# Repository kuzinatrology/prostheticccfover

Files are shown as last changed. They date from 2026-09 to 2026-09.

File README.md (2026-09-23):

# Prosthetic cover configurator

A prototype web configurator for cosmetic covers. Four tabs, one per cover,
differing in where the shape comes from: **below knee** (transtibial, the
shape of the leg set by sliders), **above knee** (transfemoral, College Park
Capital knee, the shape taken from a scan of the other leg), **anatomic
shank** (built by the offline pipeline in `anatomic/` from the prosthesis scan
and a MakeHuman shank), and **iteration 1** (a cover modelled in Rhino and
handed to the configurator as a file). Move the sliders, watch the cover turn,
read its weight, download a print file. The transfemoral and the modelled tabs
have their own sections below; everything else here applies to all of them.

The whole point of the build is the last mile: **a design that fails a
printability check is not reachable**. Every constraint is built into the
generator so no slider combination can produce one, and the interface never
tells anybody their design was rejected.

## Running it

```bash
python3 -m venv .venv && .venv/bin/pip install -r requirements.txt
.venv/bin/python -m uvicorn backend.app:app --port 8000     # geometry service
cd frontend && npm install && npm run dev                   # http://localhost:5173
```

`npm run build` puts the page in `frontend/dist`, and the service serves it
from the same port, so a built copy needs only the one process.

### Leaving it running

On macOS a launch agent keeps the service up, so the page is always at the same
address rather than only while a terminal is open:

The plist ships with a placeholder path in it; point it at wherever this is
checked out before loading it.

```bash
cp deploy/com.cover.configurator.plist ~/Library/LaunchAgents/
launchctl bootstrap gui/$(id -u) ~/Library/LaunchAgents/com.cover.configurator.plist
echo '127.0.0.1  cover.test' | sudo tee -a /etc/hosts   # http://cover.test:8000
```

`.test` rather than `.local`: macOS hands `.local` to Bonjour, and an
`/etc/hosts` entry there resolves only sometimes. `.test` is reserved for
exactly this and always does.

The agent binds `0.0.0.0`, so anybody on the same network opens it at
`http://<this machine's address>:8000`. That address comes from DHCP and can
move; reserve it on the router if it needs to stay put. `cover.test` is a line
in *this* machine's `/etc/hosts` and means nothing to anyone else's.

Nothing beyond the network is a boundary here: there is no sign-in, and every
rebuild is a couple of seconds of CPU with one worker behind it. Fine among
people who share a router, not something to put on the open internet as it
stands.

The agent has `RunAtLoad` and `KeepAlive`, so it starts at login and comes back
if it dies. It logs to `~/Library/Logs/cover-configurator.log`. To stop it,
`launchctl bootout gui/$(id -u)/com.cover.configurator`; to start it again,
`bootstrap` the same file. The port stays 8000 because binding 80 would mean
running the geometry service as root, which is not worth a shorter address.

Or skip the web app entirely:

```bash
.venv/bin/python -m backend.cli --preset chevron -o cover.3mf
.venv/bin/python -m backend.cli --image leaf.png -o leaf.3mf
.venv/bin/python -m backend.cli --operation emboss --relief-profile dome -o scales.3mf
.venv/bin/python -m backend.cli --help
```

Tests:

```bash
.venv/bin/python -m pytest tests -q
COVER_EXAMPLES=200 .venv/bin/python -m pytest tests -q      # a longer hunt
```

## Personal cabinet

The configurator now supports individual accounts. Open **Sign in / create
account** in the upper-right corner to register or sign in. The cabinet can
save the current parameter set under a name, reopen it later, and delete old
designs. Only the owner can delete a design; saved designs are publicly visible
in the community catalogue. If a design uses an uploaded image, the original
image bytes are stored with that design so it remains available after a server
restart.

For a deployed instance, set `COVER_SESSION_SECRET` to a long random value
before starting the service. The SQLite database is created at
`backend/configurator.sqlite3` and should be backed up with the rest of the
application data.

The **Community** button opens the public design catalogue. It includes every
saved design with its author nickname, a search by design name, visible 1–5
ratings, and a participant leaderboard based on average design rating. A user
can rate a design once and change that rating later.

Every nickname and design author links to `/profile/<user-id>`. Public profiles
show optional personal information, a year-long activity heatmap, and all of
the user's designs with their ratings. Profile fields are edited in the
owner's profile page; guests can only view them.

The profile avatar can be changed by clicking it and selecting an image. PNG,
JPEG, WebP and other Pillow-readable image files up to 2 MB are accepted. The
image is stored with the account and is also shown beside the nickname in the
header after sign-in.

The main screens have stable routes:

- `/workshop` — the cover configurator;
- `/profile/<user-id>` — a public user profile.

A saved design belongs to the tab it was drawn on. The tabs do not share a
parameter set -- the transtibial cover has no pylon diameter and Iteration 2 has
no calf bulge -- so each design records its tab and is read back through that
tab's own parameters. Opening a design from another tab reloads the page onto
that tab; in the catalogue such designs carry the tab's name beside them.

The header keeps **Workshop**, **Community**, and **Profile** in one responsive
navigation row. Guests also see **Sign in / Register**. After sign-in, that
button becomes the user's avatar and nickname and opens their profile; for a
guest, a profile is opened by clicking a user in Community or by visiting its
public URL.

## The four axes

A design is not a list of pattern types. It is four independent things
multiplied together, and the variety comes from the product:

```
cell field (u,v)  x  operation  x  mask (u,v)  x  finish
```

**Cell field.** Where the cells are and what shape they are: density and its
gradient, irregularity, stretch, lean, corner rounding, strut width.

**Operation.** What is done with those cells. `cut` drives prisms through the
wall and removes them. `emboss` and `engrave` displace the outer surface and
touch no boolean at all. `none` leaves the shell smooth.

**Mask.** Where the pattern lives: everywhere, in a band, on a panel front and
back, or in stripes. The edge is feathered, and that feathering is the point:
a hard edge reads as a cropped picture, a soft one reads as a designed object.

**Finish.** How it is shaded in the viewer. Flat, a gradient between two
palette colours, or faceted. None of it touches the mesh, so weight and print
file are identical across all three.

Six presets in `backend/presets.py` are starting points on those axes. Picking
one moves the sliders and lets go: nothing is locked afterwards, and the strip
stops marking a preset the moment the design has moved off it.

### The hole can be a picture

`samples/` holds a few drawings to try it on, written out of `tests/shapes.py`:
a ring whose middle would fall out, a comb whose prongs are narrower than a
strut, a disc with a whisker four pixels across.

`HOLE SHAPE: [CELLS] [IMAGE]` is not a fifth axis. Upload a leaf, a logo, a
silhouette, and it decides what a hole *looks like*; the cell field still
decides where the holes are and how big. So there is no new slider for "one
big motif or many small ones" — that is the density slider, relabelled, and
the mask, the gradient, the stretch and the lean all keep working untouched.

`backend/motif.py` reads the file. The alpha channel is believed where there
is one, because a cut-out carries its own silhouette and no threshold beats
it; otherwise Otsu's method splits the histogram and `threshold_bias` slides
that split, since on a photograph the automatic answer is often a little off
and this is the only way to put it right by hand. Whatever runs around the
border of the picture is the background. Marching squares traces the contours,
nesting sorts outlines from holes, and what comes out is a polygon in the unit
square. The file stays in memory for the session; the design carries only its
digest, which is also what goes on the spec line so the same picture and the
same sliders rebuild the same cover.

The panel shows the silhouette it read, beside the drop zone, before anything
is cut. That preview is the feature, not an ornament: without it the upload is
a black box, a cover comes back carrying something that does not look like the
picture, and there is no way to tell whether the threshold missed or the file
was wrong.

## How the geometry is put together

`backend/surface.py` builds the outer surface. The section is a superellipse,
so its sides can flatten, and its centre slides backward where the calf swells,
so the calf grows behind while the front of the shank stays where it was. The
section is walked at **equal arc length** rather than equal angle: a
superellipse parameterised by angle races through the ends of its axes, which
would stretch every cell sitting near one.

`backend/fields.py` holds the scalar fields. Density and mask are the same kind
of object, a function of (u, v) returning a number in [0, 1].

`backend/pattern.py` lays out the cells in a conformal ("Mercator") image of
the cover, `U = 2πu` and `V = ∫L dv/r(v)`, where the metric is
`r(v)²(dU² + dV²)`. A round cell there is a round cell on the cover, and cells
grow with the cover's girth.

Stretch and lean add one layer on top: seeds are laid out in a *lattice* space
and carried into the domain by a linear warp with determinant one. Cell areas
survive it, so cell counts do; adding a full turn to `U` is a pure shift in
that space, so the seam still closes however far the pattern leans; and the
cells are carried into the domain *before* anything is measured, so no
printability rule ever sees the warp.

`backend/relief.py` is the whole of emboss and engrave. For a Voronoi diagram
the distance to a cell boundary is exactly half the gap between the two nearest
seeds, so two nearest-neighbour queries give the height everywhere, and the
shell is built from a displaced grid.

`backend/mesh_build.py` closes a solid between any two grids, drives a prism
through the wall for every hole, and removes them all with one `manifold3d`
boolean. `backend/generator.py` ties it together and produces the notes.

Two details in the prisms earn their keep. A prism's caps are flat while the
wall is curved, so each cap is laid on the surface and subdivided until no
triangle outruns the curvature; without it the middle of a wide hole keeps a
lens of material floating free of the cover. And a prism's side wall is a
straight chord where the hole's edge is really a curve, so it bows into the
strut: long edges are split until that bow is small, and the remainder is paid
back in the erosion.

A cell's own hole is convex, and a cone of triangles from its centre is the
cheapest cap that covers it. A motif's hole is whatever the picture was, and a
cone from any single point folds over itself on a shape like a letter C. Those
caps are triangulated instead — a constrained Delaunay triangulation fills the
ring exactly, using the ring's own vertices, then red-green refinement splits
it until no edge outruns the same chord. Which builder a ring goes to is read
off the ring, so the cell field's own output is built exactly as it was
before, and a motif that happens to be convex costs nothing extra.

### The density field

Pattern density is a **function**, not a number:

```python
def build_cells(surface, density: Callable[[float, float], float], ...)
```

The two sliders build one. So does the mask, which is the same kind of object
used at a different point. A stress field from an FE run, or a mask painted in
the interface, is a one-line change in `fields.py`; nothing under it ever sees
a scalar.

### Irregularity

One code path covers both ends of the slider. A graded hexagonal lattice is
built from the spacing field, every node is displaced by `irregularity` times a
random offset, and the variable disk radius is then enforced directly by
pushing apart any pair that ended up too close. At 0 the lattice is untouched;
at 1 the nodes are as scattered as the spacing allows. Two damped relaxation
passes absorb the seams where the lattice has to change its column count — a
clean lattice is a fixed point of that operation, so the ordered end stays
ordered.

## The guarantees, and where each one lives

| Rule | How it cannot be broken |
|---|---|
| Strut ≥ `MIN_STRUT` | The hole *is* the cell eroded by `strut/2`, measured in mm at the cell's tightest scale. There is nothing to check. |
| Cell too small to erode | Erosion returns empty, the cell stays solid. Silently. |
| Hole < `MIN_HOLE` | Inscribed radius via `polylabel`; below the limit the cell stays solid. Silently. |
| Hole > `a_max` | The cell's seed is replaced by three and the neighbourhood is rebuilt finer. The pattern gets smaller there, not different. |
| Corner rounding | An opening (`buffer(-r).buffer(+r)`) can only take material away, so no rule needs re-checking after it. |
| Mask feathering | Fading the mask deepens the same erosion. Half a mask is half a cell gone, whatever the cell's size, and a mask at zero closes it completely. |
| Wall vs curvature | `wall_thickness`'s upper bound is recomputed from the surface's smallest radius of curvature and sent to the panel, which shortens the slider's track. |
| Groove vs wall | `relief_depth`'s upper bound is 60% of the wall when engraving, by the same moving-track mechanism. Embossing has no ceiling: it removes nothing. |
| One connected piece | Voronoi edges form a connected graph, so the shell cannot fall apart. Confirmed by genus: it comes out at exactly one per hole plus one for the tube. |
| Mesh edges eating the strut | Ring edges are split until their bow is under a fixed fraction of the strut, and the erosion is widened by exactly that fraction. |
| A picture's own thin details | The motif is opened by `MIN_HOLE/2`. An opened shape is a union of discs of that radius, so nothing in it can be thinner. |
| A picture's own thin gaps | The motif is then closed by `strut/2`. The complement of a closed shape is a union of discs, so no gap in it can be narrower. |
| A motif wider than the wall | Its own fill is cut back in that cell and it is laid again. Subdividing is for cells; half a leaf is not a leaf. |
| A hole inside a hole | Filled. It is a disc of shell with nothing holding it, and it would drop out of the print. |

`a_max` is `STIFFNESS_C · t^1.5` (a plate deflects as span² and stiffens as
t³), capped by the bridging limit relaxed by an arch factor, and capped again
at 90% of the surface's radius of curvature so a hole cannot outgrow the wall
it is cut through. A squarer section curves harder at its corners, so it gets
a finer pattern; that is the physics, not a rule bolted on.

Every millimetre-to-domain conversion is **measured from the surface**, not
guessed from the section's half-widths. That was an ellipse-only shortcut, and
it stopped being an upper bound the moment the section could be a superellipse.

When something does move, the panel says so as a property of the object —
`Struts widened to 0.8 mm`, `Relief held at 1.4 mm by the wall`, `Pattern
refined across 12 cells for stiffness`, `Thin details below 1.5 mm removed`,
`Using 12 largest shapes of 47`. The words "error", "invalid" and "failed"
appear nowhere in the interface.

There is one check in the codebase, `generator.audit`, and it is aimed at us:
watertight, consistent winding, expected body count, positive volume, and for
a solid operation the topology of a plain tube. It runs before any file is
written. A failure is a generator bug and is logged with the full parameter
set. The user still gets their file.

## Printer profile

`backend/printer_profile.py` holds every calibration constant. **The values
are preliminary** — educated starting points for a 0.4 mm nozzle — and are
meant to be replaced after a calibration print: a plate of struts 0.4–1.6 mm,
holes 1.0–4.0 mm, and a three-point bend coupon at each wall thickness.
`PrinterProfile` is a dataclass so several can coexist.

## Weight

Weight is shown against the same shape left plain. Cutting takes material away
and the panel reads `77 % lighter than plain`; raising a relief puts material
on and the same line reads `+154 g heavier than plain`. One reference, two
wordings, chosen by the sign.

## Tests

`pytest` drives `hypothesis`, which picks the parameters across every
operation, every mask mode and every range. The properties:

1. Closed, correctly wound, and in one piece — two when a split was asked for.
2. Struts at least `MIN_STRUT` wide.
3. No hole wider than `a_max`.
4. No hole below `MIN_HOLE`.
5. Positive volume, and below the plain volume wherever material was removed.
6. In a solid operation, nothing goes through the wall: the cover is still one
   tube with an opening at each end and no other hole in it.
7. An engraved groove never leaves the wall below 40% of itself.
8. A masked panel keeps the pattern inside its own angular width.
9. All six presets build, pass everything above, and export.

`tests/test_motif.py` states them again for an uploaded picture, over shapes
picked to break each one: a whisker four pixels across, a comb whose prongs and
gaps are both narrower than a strut, a dumbbell whose bar the opening severs, a
crescent no cone of triangles can cover, a ring whose middle would fall out,
and a sheet of white paper. The pictures are drawn in `tests/shapes.py` rather
than committed, so the suite carries no binary and every shape says in code
what it is there to break.

The measurements come from `backend/measure.py`, which works on the real 3D
positions of the hole boundaries and probes the wall by firing rays at the
finished mesh, rather than reusing the generator's own arithmetic. A mistake in
that arithmetic cannot hide behind a test that shares it.

Anything that fails is appended to `tests/regressions/corpus.jsonl` and re-run
from then on, a few cases per kind of failure so the suite stays quick. Five
bugs went in that way, each one caught by the engine rather than by hand:

1. Flat prism caps left a lens of material floating inside every wide hole.
2. Cutting the seam shed strut fragments that belonged to neither half.
3. On a slim cover the hole span outgrew the curvature and the prisms drove
   into the opposite wall.
4. Straight mesh edges bowed into the struts from both sides and met in the
   middle, cutting a strut the pattern had sized correctly.
5. On a superellipse section the millimetre-per-domain-unit bound stopped
   being a bound, and holes came out wider than the wall could carry.

The last two are the reason the corpus is worth keeping. Every property held on
the ideal geometry; only the built object was wrong.

## Interface

`frontend/src/strings.en.ts` holds every visible string. **An empty string
means the element is not rendered at all** — no gap, no empty node, no markup
change. `readout.triangles` ships empty as a demonstration: the triangle count
simply is not there. The rule holds for controls too, so clearing the download
label removes the button rather than leaving a blank slab of colour.

The page is an orthopaedic order form: a narrow column of label-and-value rows
over the model. The hairline rules that separate the rows *are* the sliders, so
the one saturated thing on the page — the colour of the cover — runs along the
form's own structure. Picking a material recolours the tracks, the thumbs, the
choice strips, the note marks and the download button. Weight and the balance
against a plain cover sit in the sticky footer, where an order form puts its
total. Rows that the current operation has nothing to say about are hidden
rather than greyed.

`frontend/src/presets.ts` holds only the drawings on the preset tiles: small
deterministic pictures of what each one does, in the shape of a cover. The
values themselves come from the server.

Dragging a slider requests a draft mesh after 250 ms; releasing it requests the
full one. Changing the finish requests nothing at all — it is shading, and the
browser does it. Auto-rotation stops on first touch and never starts under
`prefers-reduced-motion`.

## Known limits

- Rebuild time is one to three seconds over most of the range. The far corner —
  longest, widest, thinnest wall, densest pattern, about 3300 holes — takes
  about five, which misses the two-second target and is stated here rather than
  hidden. Most of it is the boolean. The obvious next move is to keep the shell
  and re-cut only the cells a change touched.
- The graded hexagonal lattice follows density along `v` only. A density field
  that varies around the circumference is honoured by the jitter and the
  spacing, but not by the lattice's column count, so a `u`-varying field at
  `irregularity = 0` will be approximate.
- The dynamic ceiling on `wall_thickness` is real but rarely binds inside the
  declared ranges. The mechanism is there for wider ranges and for
  scan-driven surfaces later; its narrowed track has been exercised. The
  ceiling on `relief_depth` binds routinely.
- Corner rounding is scaled by the hole's own inscribed radius rather than by
  the printer's minimum strut, which the brief suggested. At real cell sizes
  the latter is invisible.
- Faceting bins triangles into hexagons on the surface and averages their
  normals. The mesh is untouched, as specified, so facet edges follow the
  underlying triangulation and are slightly ragged up close.
- A picture only reaches the geometry under `cut`. Raising and sinking read the
  cell field directly, without ever building a polygon, which is what makes
  them fast; a motif there would mean a second relief path for one operation.
- An SVG is rasterised at the working size and traced like everything else,
  rather than having its paths imported. At 512 pixels under the smoothing
  slider the difference does not survive to the print, and it keeps one code
  path instead of two.
- The picture lives in memory for the life of the process, eight uploads at a
  time. A design opened later still carries the digest but not the file, and
  falls back to cells with a note saying so.
- Printability was verified by round-tripping 3MF and STL back through trimesh
  (watertight, consistent winding, expected body count, matching volume, and
  the colour written as a 3MF base material). It has not been through a slicer
  or a printer.

## The transfemoral tab

`backend/transfemoral/` is a second pipeline beside the first. It shares the
cell field, the masks, the relief, the prisms, the motif reader and the
printer profile, and adds what a scan and a knee need. Nothing about the scan
or the knee reaches the interface: the person choosing sees the design
controls, a surface smoothing slider and an **Attachment** group.

```bash
.venv/bin/python -m tools.prepare_scan --render renders/stage_1   # once per scan
.venv/bin/python -m tools.stage_renders                          # stage renders + numbers
TF_EXAMPLES=20 .venv/bin/python -m pytest tests/test_transfemoral.py -q
```

### The scan

`tools/prepare_scan.py` reads `data/оболочка.stl` and writes
`backend/assets/leg_surface.npz` (radius over angle and height about a
centreline) and `leg_surface.json` (what each step found). Every step has a
flag. Mirroring is **off** for this file: it is already the mirrored copy of
the original scan, confirmed as the prosthetic side.

Front and back: the two indicators the brief names — the direction of the
largest radius over the calf and the drift of the section centres — agree to
6.4 degrees, and on this scan both point at the tibial crest, i.e. forward. A
shin section is long front to back and the crest reaches as far from the axis
as the calf does. They are used for the front-back line and for the
20-degree agreement check; which end is the back comes from two independent
cues that must agree: where the section's mass sits (the calf), and which way
the scan runs above the knee (the thigh). The blind spot then lands behind the
knee, as the brief says it should.

The knee axis sits over the last trusted section centre (z = 20), not on the
tangent carried up past it, which is the calf's forward drift into the knee
and would put the axis a centimetre in front of the joint.

Curvature is read over a 6 mm baseline: the scan's triangles are 8 mm across
and read point by point they have a 2 mm radius at every corner, which would
cap the wall and every hole at nothing.

**Evening out the knee.** Above z = 40 the probe rays start missing: the knee
is bent, the thigh shadows the back of it, and only a third of the ring is
seen behind the joint at z = 65. The gaps were filled, so rows two millimetres
apart came out up to eight millimetres apart, which showed as a wavy top rim
and a rippled surface over the whole upper third. `even_out_knee` builds the
surface **out** to a smooth envelope over it — dilate, then a 9 mm Gaussian
along the height and a 4 mm one around the section — faded in over 25 mm so
the shin below never moves, and capped at `KNEE_EVEN_MAX_SHIFT` (6 mm).

Out, never back, and the asymmetry is the whole point. Shaving the spikes
would even the rim just as well, but this surface is the cover's outer skin
and its wall goes inward from it, so a millimetre shaved here is a millimetre
off the room left for the knee module inside — and that clearance is thin
enough that three millimetres of shaving put the front half into the module on
several of the corpus's parameter sets. Filling can only add room. The price
is a knee up to 6 mm fuller, 0.8 mm on average. It runs before the smoothing
slider and whatever the slider says: these are the scan's shadows, not the
skin texture the slider is about. What is left rough is the hollow behind the
knee, which the notch cuts away. Below z = 40 nothing changes.

**Known limitation.** From z ≈ 20 up to `top_z` the scan is the knee bent to
114 degrees: the kneecap is displaced, the front is stretched, the outline is
not a straight knee's. It is the most visible part of the cover. The data
cannot correct it and straightening by rotation is worse. To be revisited with
a new scan.

### The notch

The cover is rigid and crosses a joint, so behind the knee it leaves free a
sector with its apex on the flexion axis at least as wide as the flexion. That
sector (grown by `notch_fillet`) is the notch, **together with** everything the
thigh stand-in sweeps through from 0 to `flexion_angle`, plus
`notch_clearance`. The sector alone does not clear the brief's own rotation
test: a leg-radius cylinder above the knee is wider than the shin in places,
and turning it sweeps its sides across the shin's side walls just below the
sector's lower edge. No sector can: it would need to open 106 degrees below
the horizontal and 88 above.

The thigh's radius is half the knee's width across, at the axis (56 mm), not
the mean radius at `top_z` (67 mm): that section is the bent knee with the
thigh and the filled blind spot in it, and a cylinder that size bit the front
half into a waist.

`notch_split` is 0.35, set from the first renders: at 0.5 the notch ran down
the calf almost to the ankle and left the back half a thin U.

Notch, seams and rims are fields over the unwrapped surface, in millimetres,
and they are what the pattern's mask is made of: rims and seams fade the cells
over 14 mm, the notch over 35 mm. A hole is then kept only if its whole outline
stays a strut from every edge.

Two more rules apply to this cover alone, because a fading cell erodes from its
rim inward and the last ones before the pattern stops come out as splinters
that pass `MIN_HOLE` and still read as chips in the edge rather than as holes.
A hole narrower than `MIN_TIDY_HOLE` (3 mm across, measured as the widest
circle it holds, in millimetres at its own place on the leg) is left solid; so
is one the fade is eating that is narrower than `TIDY_ASPECT` of its own
length. Outside the fade the shape rule never applies, so a design of
deliberately long cells keeps them. On the default cover the two together
leave 40 cells of 551 solid and the pattern ends on whole holes.

### Halves, magnets, clamps

The seams follow the centreline down each side, passing through the knee
axis at `seam_offset` = 0, and **both** end where the first of them runs into
the notch. The notch is a sector cut at an angle, so it crosses one seam tens
of millimetres below the other: on this scan at z = 7 and z = 57. Ended side
by side, the back half kept a tail between those two heights that narrowed
from a quarter of the turn to a point — a fin that prints badly, snaps easily
and reads as a mistake. Ending both together squares the back half off at
z = 7. `seam_offset` stops where the back half would keep less than a quarter
turn. Every half is a slab: a region of the surface between two offsets along
its normal, triangulated with interior points a chord apart and refined on the
surface.

The shelf under each seam is `magnet_diameter + CLEARANCE + 2 MIN_STRUT` wide
(the brief's width without the fitting gap leaves the strut beside the socket
short by half of it). The back half thickens inward under each socket; the
shelf sits deeper by that thickening plus the gap, so the back half slides
over it. Sockets are cylinders on one surface normal. The shelf breaks where
a clamp passes and gives way to the tube near the ankle; magnets are spread
along what is left.

A shelf that simply stopped left an 8 mm step in the outline of the half, once
per clamp, which is the first thing the eye finds on a part that is otherwise
a smooth curve. It now narrows into every break over `SHELF_RAMP` (14 mm) down
to `SHELF_STUB` (a quarter) of its width, so the step left is 2 mm rather than
8. Not to nothing: a shelf run out to a point would end in a wedge thinner
than a strut, which is what stopping it short was avoiding in the first place.
A magnet needs the shelf at full width under it, so it stands `SHELF_RAMP`
plus its own half width clear of a break rather than the half width alone.

Clamps sit on a line from the ankle's centre to the knee axis (7.5 degrees off
the scan's axis), at right angles to it. The tube is 30 mm; the module is
preliminary 60 × 65 mm (**neither is measured**: 65 is scaled off a
photograph, 60 is a guess), and its hole's defaults carry 2 mm extra. Ring,
lugs and ribs come from the room at that height and MIN_STRUT; a height where
they do not fit is not reachable, and the slider's track says so. The lower
clamp keeps out of the sector. The upper one cannot: it holds the module, and
the module itself stands in the sector, fixed to the shin, where no thigh ever
reaches.

### Output

Four bodies: front half (with shelves, sockets and both clamps' front parts),
back half, and the two clamps' back parts. Download all of them as a zip of
3MF (or STL) with their masses, or each on its own. The viewer mesh is
simplified to 0.3 mm, about a tenth of the print mesh's triangles.

### Tests

`tests/test_transfemoral.py` runs `tests/tf_properties.py` over random
attachment and design settings: every body closed; no vertex of a half in the
sector; the thigh turned from 0 to the flexion angle touches nothing; walls,
including behind every socket, at least MIN_STRUT (by rays through the mesh);
socket pairs on one axis; no body into another, the tube or the module; the
back parts of the clamps and the bolt heads at least CLEARANCE from the back
half; holes a strut from each other and from every edge. Counterexamples go
to `tests/regressions/tf_corpus.jsonl`. The first run found six, of four
kinds, all fixed: the rectangular hole's round corners clipping the module's
square ones; shelves running into the tube at the ankle; the notch read at
two depths when the swept thigh is not monotonic through the wall; and rays
through a shared mesh edge counted as a wall a hundredth of a millimetre thick.

## The modelled tab

`backend/iteration1/` is the other way round from every tab before it. The
first draws a cover from sliders, the second and third derive one from a scan;
this one is handed a cover that someone already modelled — `cover ready
iteration 1.stl`, exported from Rhino — and its job is to keep that shape, let
it be worn differently, and put a wall and a pattern on it. The design
controls are the shared ones; what is gone is every control that would draw a
silhouette from nothing.

```bash
.venv/bin/python -m backend.iteration1.prepare     # once per model file
.venv/bin/python -m pytest tests/test_iteration1.py -q
```

### Reading the file

`prepare.py` scatters three million points over the export's faces and bins
them by angle and height about a fitted centreline. In each cell the samples
split into two skins at the midpoint between the nearest and the farthest, and
each skin is the **mean** of its own samples: taking the extremes rings, since
the farthest of nine samples on a slanted triangle sits high by a fraction of
that triangle and which fraction depends on where the export's rows fell. The
result is `backend/assets/iteration1.npz` — outer radius, wall, coverage,
centreline and the two rim curves — and `iteration1.json`, what it found.

The file is a closed cover with a 4.9 mm wall, 462 mm tall, whose top rim runs
from 323 mm at the back of the knee to 457 at the sides. Read back, the stored
surface sits 0.01 mm from the model's outer skin at the median and 0.05 mm at
the 95th percentile, against triangles of the export that are millimetres
across.

Angles are stored over 0 to 2 pi, the range the surface reads them back in.
Stored over -pi to pi they would land outside the spline's knots for half the
turn and be extrapolated instead of read, and half the cover would come out
invented — which is what happened, and is what `test_the_stored_surface_is_the_modelled_one`
now holds down.

### Wearing the file differently

The shape is the file, but that is not the same as the shape being fixed. The
**Silhouette** and **Rim and notch** groups hold eight knobs, and every one of
them is a transformation of the measured surface rather than a shape of its
own: girth (`fullness`), the section squashed front to back or side to side
(`ovality`), how much of the swell is carried behind the axis
(`posterior_bias`), the turn between the two rims (`twist`), the cover
stretched along its axis (`height_scale`), and three cuts — `top_trim`,
`bottom_trim` and `notch_deepen`. So no slider can invent a cover the file
does not have: a fuller cover is this cover fuller.

They are applied to the section about its own centre in the transtibial
surface's order, so a design reads the same on this cover as on that one, and
the surface is cached on all eight together — moving a pattern slider re-reads
the same shaped surface instead of building it again.

`notch_deepen` is the one worth spelling out: it lowers the rim in proportion
to how much of a notch the rim already is at that angle, so the deepest point
moves by the whole slider and the high sides do not move at all. The trims
cannot make the two rims cross; a column is never left shorter than 30 mm.

### Starting points

The same six presets the other tabs offer — Lattice, Chevron, Scales, Vent,
Facet, Ridge — carried over by key through `backend/iteration1/presets.py`,
the way the transfemoral tab carries them. Every value in every one of them
survives the carry: a preset is made of design values, and this cover has all
of them. A preset moves the pattern and nothing else, so where the shape
sliders were left is where they stay.

### The rims

The two rim curves are what makes this cover different from a tube, and every
field that decides where material and holes may go is read from them rather
than from a grid: `edge_distance(u, v)` is the height to the nearer rim.
Cells fade out over 14 mm toward it, a plain band the **Plain band at the rim**
slider wide is left solid, and a hole is kept only if its whole outline stays
that band plus a strut clear. So the pattern ends on whole holes and the edge
is an edge.

### The wall

Laid down the radius, not along the normal. The cover is star shaped about its
axis and its walls stand within a few degrees of vertical, so a smaller radius
is what a wall inward means. Offsetting along the normal is what a general
solid would need and it is exactly what goes wrong here: over the rim the
normal turns up across the edge, and a skin offset along it climbs above the
rim and crosses the skin it came from — a rim of spikes. How much of the
normal is radial is divided back out so the wall measured across the skin is
the one the slider asks for; it is read a few millimetres inside the rim,
where the surface is the shape rather than the edge, and smoothed around the
section, because a wall that changes by a tenth of a millimetre per column is
a rippled rim band.

The slider starts on the wall the model was drawn with and reaches 8 mm rather
than the 4 mm the other tabs stop at: a range that could not reach the file's
own wall would refuse the model on the way in. Where the curvature of the
model binds first, the generator says so and the panel shortens the track.

### Output

One body, so one file: 3MF with the cover's colour, or STL. The plain shell
rebuilt from the grid holds 672 cm3 against the file's 676, the difference
being the wall measured across the skin rather than along the radius. A cut
pattern at the default density takes that to about 420 g in PETG, half the
plain weight, over roughly 3300 holes.

A draft takes about 20 seconds against 8 for the transfemoral tab and 5 for
the transtibial one. Nothing here is slower than those; the cover is simply
the largest surface in the app and carries the most cells, and most of the
time is in the shared pattern builder.

### Tests

`tests/test_iteration1.py` holds the two kinds of claim apart. That the tab
still describes the file: the stored surface is the model's skin, the rims are
the model's rims, the plain shell is the model's solid. And the claim every
tab makes: each operation gives one closed body, no hole opens onto a rim, the
wall measured by rays through the solid is the wall asked for, no setting at
the end of a range refuses a cover, and the smoothing slider never moves the
surface more than half a millimetre off the file.

## Out of scope

No topology optimisation, no FE, no accounts, no database, no
payments, no phone layout. The fields are the seam the first two would come in
through, and they are deliberately left open.

For an uploaded picture in particular: no background removal by a network, no
object recognition, no colour tracing, no contour editor in the browser. When
the automatic threshold misses on a photograph, the answer is the threshold
slider and the preview beside it.

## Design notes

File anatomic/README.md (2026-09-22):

# Оболочка голени для трансфеморального протеза

Шесть этапов, каждый — отдельный скрипт, каждый перезапускается сам по себе.
Промежуточные результаты лежат в `anatomic/work/`, рендеры и отчёты —
в `anatomic/renders/`. **Все параметры в одном файле: `anatomic/config.py`.**

```bash
.venv/bin/python -m anatomic.run_all          # всё подряд
.venv/bin/python -m anatomic.stage4_surface   # или по одному
```

| Этап | Скрипт | Вход | Выход |
|---|---|---|---|
| 1 | `stage1_prepare.py` | `data/Leg_Prosthetic.stl` | `work/stage1_prosthesis.stl`, `work/stage1.json` |
| 2 | `stage2_sections.py` | этап 1 | `work/stage2_prosthesis.stl` (начало координат на оси колена), таблица сечений |
| 3 | `stage3_profile.py` | MakeHuman + `data/ref_*.png` | `work/stage3_profile.npz` |
| 4 | `stage4_surface.py` | этапы 2 и 3 | `work/stage4_surface.stl` |
| 5 | `stage5_flexion.py` | этап 4 | `work/stage5_surface.stl`, глубина выреза |
| 6 | `stage6_shell.py` | этапы 4 и 5 | **`cover_anatomic.stl`** |

## Системы координат

- Этап 1 ставит z вдоль пилона, y вперёд (по носку стопы), ноль на верху пилона.
- Этап 2 переносит начало координат **на ось колена**: z вниз отрицательный,
  x вдоль оси колена, y вперёд. Дальше всё в этой системе.

## Что чем задаётся

- **Абсолютный размер** — протезом: каждое сечение раздувается ровно настолько,
  чтобы вместить сечение протеза плюс `CLEARANCE_MM`.
- **Форма сечения и пропорции по высоте** — базовой сеткой MakeHuman (CC0),
  только отношения, без абсолютных размеров.
- **Кромка** — гладкой периодической кривой через 6 контрольных точек
  (`config.rim_control`). Сетка строится так, что каждый столбец заканчивается
  точно на кривой, поэтому край не повторяет треугольники.

## Главные ручки в `config.py`

| Параметр | Что делает |
|---|---|
| `CLEARANCE_MM` | зазор между протезом и внутренней стенкой |
| `WALL_THICKNESS_MM` | толщина стенки |
| `COVER_SECTION_STEP`, `COVER_ROWS` | густота сечений и строк сетки |
| `COVER_FULLNESS` | общая полнота силуэта (икра) |
| `RIM_FRONT_DIP_MM`, `RIM_NOTCH_DEPTH_MM` | передний спуск и глубина заднего выреза |
| `ANATOMY_T_BOTTOM` | на какой высоте голени MakeHuman сидит низ оболочки |
| `BOTTOM_CLEARANCE_MM` | насколько низ выше адаптера стопы |
| `GIRTH_SMOOTH_MM`, `CENTRELINE_SMOOTH_MM` | сглаживание по высоте |

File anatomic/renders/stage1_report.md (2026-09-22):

# Этап 1 — подготовка скана протеза

Скрипт: `anatomic/stage1_prepare.py`, параметры: `anatomic/config.py`,
результаты: `anatomic/work/stage1_prosthesis.stl`, `anatomic/work/stage1.json`,
рендеры: `anatomic/renders/stage1_{front,side,three_quarter}.png`.

## Входные файлы

В проекте файлов с именами из задания не было. Нашёл их под другими именами:

| В задании | Что нашёл | Скопировано в |
|---|---|---|
| `Leg_Prosthetic.stl` | `~/Downloads/Telegram Desktop/Leg+Prosthetic.stl`, 124 МБ | `data/Leg_Prosthetic.stl` |
| `capital_knee.pdf` | `~/Desktop/протез/документация протеза.pdf` | `data/capital_knee.pdf` |
| `ref_1.png`, `ref_2.png` | на диске нет | — |

Оригиналы не менялись, скрипт работает с копиями.

**Документация сошлась полностью** (стр. 3–4): Flexion 130°, Overall height
230 mm, Dome to knee center 17 mm, Knee center to pyramid center 7 mm,
34 mm Pylon, вес узла 980 г.

## Что на самом деле в скане

Описание скана в задании не совпало с файлом. Факты:

| Параметр | В задании | В файле |
|---|---|---|
| Треугольников | ~2,5 млн | 2 479 547 |
| Отдельных кусков | 111, в основном мусор 1–2 треугольника | **3**, самый мелкий 56 816 треугольников |
| Замкнутость | не замкнут | не замкнут, подтверждаю |
| Нормали | смотрят внутрь | подтверждаю, объём −1.0·10⁸, развернул |
| Единицы | вероятно мм | **мм**, доказано пилоном (см. ниже) |
| Содержимое | протез, в главном куске слиплись обе ноги | **целиком сидящий человек**: обе ноги, обе руки, костыль, сиденье, обувь |

Мусора из 1–2 треугольников в файле нет вообще, так что чистка свелась к
выделению нужного куска, а не к отсеву обрезков.

Габарит сцены 1054 × 1117 × 859 мм, система координат произвольная.

## Как нашёл протез

Протез — это одна нога сидящего человека, слипшаяся с остальной сценой в
главном куске. Отделил так:

1. Две опорные точки (в гильзе и в стопе) сняты с размеченных рендеров сцены,
   лежат в `config.LIMB_SEED_TOP` / `LIMB_SEED_BOTTOM`.
2. Цилиндр радиусом 110 мм вокруг отрезка между ними.
3. Из того, что попало в цилиндр, беру наибольшую связную компоненту —
   шорты, сиденье и вторая нога отваливаются как отдельные поверхности.

Получилось 1.4 млн треугольников, прорежено до 120 000.

## Единицы и вертикаль

Единицы определены **по пилону**, а не по росту: это единственная деталь с
каталожным размером. Ищу самый длинный участок, где сечение круглое и
постоянное, — он нашёлся длиной 115 мм с размерами **36.7 × 32.8 мм** при
каталожных 34 мм. Значит миллиметры.

По этому же участку выровнена вертикаль: пилон — единственная заведомо прямая
часть протеза, поэтому ось z ведётся по нему, а не по линии «гильза—стопа»
через согнутую ногу. Уточнение оси сдвинуло её на 8°.

Направление «вперёд» взято по стопе: она заметно длиннее в сторону носка, чем
в сторону пятки, поэтому главное направление отпечатка стопы со знаком по
длинному концу — это перёд.

Начало координат: z = 0 на верхе пилона. (Ось колена будет найдена на этапе 2,
тогда же начало координат переедет на неё.)

## Части протеза

Границы найдены по профилю сечений с шагом 5 мм, не на глаз:

| Часть | z, мм | Длина | По чему найдена |
|---|---|---|---|
| Гильза бедра / бедро | +249 … +490 | 241 мм | выше перехвата |
| Колено | 0 … +249 | **250 мм** | от верха пилона до перехвата |
| Пилон | −115 … 0 | 115 мм | круглое постоянное сечение 34 мм |
| Адаптер стопы | −230 … −115 | 116 мм | от низа пилона до обуви |
| Стопа (в кроссовке) | −357 … −230 | 127 мм | сечение шире 90 мм |

Колено 250 мм против каталожных 230 мм — расхождение 9%, объяснимо тем, что
сверху к модулю прилегает низ гильзы, а снизу зажим трубы.

## Что стоит проверить глазами

1. **«Гильза бедра» — это не гильза, а шорты и бедро поверх неё.** Жёсткой
   гильзы в скане не видно: она под одеждой. Для оболочки голени это не
   критично (она кончается ниже), но на этапе 5 гильза нужна как объект
   столкновения, и её придётся задать цилиндром по внешней поверхности.
2. **Стопа в кроссовке.** Низ оболочки придётся ставить выше кроссовка, а не
   выше настоящего адаптера стопы.
3. Проверить по рендерам, что нога опознана верно.

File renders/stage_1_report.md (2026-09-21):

# Этап 1. Подготовка скана

`tools/prepare_scan.py`: из `data/оболочка.stl` (это `оболочка (3).stl`) получаются `backend/assets/leg_surface.npz` и `leg_surface.json`.
Рендеры: `stage_1_side.png`, `stage_1_front.png`, `stage_1_back.png`.

| Шаг | Результат |
|---|---|
| Единицы | мм, длина вдоль главной оси 520.6 |
| Выравнивание | главная ось (0.3325, 0.9414, 0.0574), z от −311.7 до +208.8 |
| Перёд и зад | признаки из ТЗ дают −137.4° (макс. радиус у икры) и −131.0° (снос центров), расхождение **6.4°** |
| Знак «зад» | масса сечения −1.07 мм, бедро −27.6 мм: оба признака согласны, **зад лежит на +45.8°**, то есть с противоположной стороны от признаков из ТЗ (см. ниже) |
| Зеркалирование | выключено: файл (3) уже отражён |
| Ось | 64 сечения ниже z=20, касательная по участку [−60, 20], снос центров от прямой оси 7.0 мм, от главной оси 27.9 мм, средний радиус 49.0 мм |
| Обрезка сверху | top_z = 105, граней было 5252, осталось 4074 |
| Бедро | 413 вершин дальше 1.5 × r, 476 граней и 39 мелких компонент удалены |
| Низ | bottom_z = −303 (нижний ряд со 100% покрытием) |
| Прореживание | не нужно: 3559 граней при рабочем числе 60 000 |
| Звёздчатость | 0 проблем на 145 160 лучах |
| Покрытие лучами | z=70: 100%, 75: 95.3%, 80: 92.2%, 90: 88.9%, 100: 86.9%, 104: 86.4% (ТЗ: 100 / 93 / 90 / 88 / 86) |
| Дыра | в 22 рядах; самая широкая 83°, **вне выреза 10°** (ТЗ: около 16°) |
| Сглаживание | по умолчанию смещение по нормали 0.433 мм, на максимуме ползунка 0.466 мм, предел 0.5 |
| Колено | сечение на оси: 152.9 мм спереди назад, 112.8 мм в поперечнике; задняя поверхность на 87 мм позади оси; при 145° вырез на спине идёт по высоте от −206 до +346 |

## Отклонение от ТЗ: знак направления «назад»

Оба признака из ТЗ (направление максимального радиуса у икры и снос центров от главной оси) действительно сходятся (6.4°). Но на этом скане они указывают **вперёд**, на гребень большеберцовой кости. Сечение голени вытянуто спереди назад, и гребень отстоит от оси так же далеко, как икра. К тому же главную ось наклоняет масса согнутого бедра. Если построить по ним, слепая зона и остаток бедра оказываются спереди, а вырез ложится на надколенник.

Поэтому признаки из ТЗ задают линию «перёд–зад» и проверку расхождения на 20°. Сторону «назад» выбирают два независимых признака: где лежит масса сечения (центроид относительно середины его протяжённости) и куда уходит бедро выше оси колена. Если они расходятся, скрипт падает. Для этого скана итог сверен с положением слепой зоны: она сзади, в пределах −88…+27° от «назад», как и написано в ТЗ.

## Известное ограничение

От z ≈ 20 до top_z колено снято согнутым на 114°. Записано в JSON (`known_limitation`), в докстринг скрипта и в README.

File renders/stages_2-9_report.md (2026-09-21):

# Этапы 2–9. Кавер трансфеморального протеза

Все этапы пройдены подряд, без остановок. Рендеры лежат в `renders/stage_N_*.png`, числа в `renders/stages.json` (их пересчитывает `python -m tools.stage_renders`). Этап 1 описан в `stage_1_report.md`.

## Этап 2. Вырез под сгибание (`stage_2_*`)

- Ось колена: y = 27.2, z = 70. Взята над последним доверенным центром сечения (z = 20), а не на касательной, продолженной вверх: касательная переносит на ось снос «икра → колено» и ставит её на сантиметр впереди сустава.
- `flexion_angle` = 145, `notch_split` = **0.35**, кромки сектора −50.8° и +94.2°, `notch_fillet` = 4 мм.
- **Отклонение от ТЗ: вырез — это сектор плюс объём, который заметает бедро.** С одним сектором проверка поворотом не проходит. Цилиндр бедра местами шире голени и при повороте проходит боками через её боковые стенки сразу под нижней кромкой сектора. Сектору для этого пришлось бы раскрыться на 106° вниз и на 88° вверх, то есть больше 180° в сумме. Поэтому вырез = сектор (со скруглением) ∪ всё, что заметает бедро на 0…145°, с зазором 2 мм. Всё задаётся параметрами из конфига.
- **Радиус бедра = половина ширины колена поперёк (56.5 мм).** Средний радиус на top_z равен 67 мм, но это сечение согнутого колена со слепой зоной внутри. Цилиндр такого размера выгрыз переднюю половину в «талию».
- `notch_split` 0.35 подобран по рендеру, как и предусматривает ТЗ. При 0.5 вырез доходил почти до лодыжки, и задняя половина превращалась в узкую букву U.
- Шов упирается в вырез на z = 7 (сторона +x) и z = 57 (сторона −x). Стороны несимметричны, потому что несимметрична сама нога.
- Замечено: на стороне −x шов подходит к скруглённой вершине сектора, и на кромке виден небольшой «крючок». Если сдвинуть шов назад (`seam_offset`), точка встречи опускается.

## Этап 3. Стенка (`stage_3_*`)

- Снаружи поверхность скана один в один, стенка откладывается только внутрь. Каждое тело — «плита» над областью развёртки между двумя смещениями по нормали, замкнутая по всем кромкам.
- Стенка 2.4 мм. Потолок ползунка 4.0 мм: радиус кривизны на базе 6 мм равен 15.8 мм, это ахиллово сухожилие.
- Объёмы гладкого варианта: передняя половина 236 909 мм³, задняя 73 153 мм³.
- На разрезе сбоку видны полки вдоль швов.

## Этап 4. Половины и шов (`stage_4_*`)

- Шов идёт вдоль линии центров и на высоте оси проходит через ось колена. Предел `seam_offset` 14 мм: при нём задней половине остаётся минимум 90° окружности.
- Зазор в шве = CLEARANCE 0.3 мм.
- Гладкая полоса у шва: минимум 9.7 мм. Это полка, зазор и 1.5 мм бокового запаса: на вогнутой поверхности детали, построенные по нормалям, на глубине расходятся вбок, и без запаса утолщение задней половины встречалось с полосой полки.
- Узор гаснет у ободов и швов на 14 мм, у выреза на 35 мм. Отверстие остаётся, только если весь его контур не ближе ширины перемычки к любой кромке.
- 551 отверстие: 446 на передней половине, 105 на задней.

## Этап 5. Магниты (`stage_5_*`)

- Ширина полки 7.9 мм. **Отклонение:** по формуле ТЗ `d + 2·MIN_STRUT` гнездо диаметром d + CL оставляло рядом стенку на 0.15 мм тоньше MIN_STRUT, поэтому к ширине добавлен зазор.
- Утолщение задней половины 4.96 мм. Полка лежит на глубине 5.26…10.21 мм, гнездо 6.3 × 3.3 мм.
- Магниты стоят на z = −206 / −128 / −44 (сторона +x) и −283 / −192 / −101 / −10 (сторона −x). Полка прерывается там, где проходит обойма, и заканчивается, не доходя до трубы у лодыжки. Магниты расставляются по оставшейся длине. При настройках по умолчанию нижний магнит на стороне +x не поместился рядом с трубой, заметка: «7 magnets placed of 8».

## Этап 6. Обоймы (`stage_6_*`)

- Линия пилона идёт от центра лодыжки к оси колена, наклон 6.1°. Низ модуля на z = −85 (по мануалу Capital: 173 − 17 = 156 мм от центра колена).
- Нижняя обойма: z = −225, допустимо −234…−201, кольцо 3.45 мм, 2 перемычки.
- Верхняя обойма: z = −60, допустимо −66…+70, кольцо 2.4 мм, 3 перемычки.
- Болты на 19.5 и 35.5 мм от оси, высота обоймы 10 мм.
- **Отклонение:** у верхней обоймы нет запрета на сектор. Её держит модуль, а модуль сам стоит в секторе, закреплён на голени, и бедро туда не заходит. Нижняя обойма сектор соблюдает.
- Верхняя обойма видна в проёме выреза.
- Минимальный размер прямоугольного отверстия поднят до 60.8 × 65.8 мм, чтобы скруглённые радиусом MIN_STRUT углы обходили прямые углы модуля.
- **60 × 65 мм по-прежнему не замеры.** В конфиге и в README это помечено.

## Этап 7. Выход (`stage_7_*` — разнесённый вид)

| Тело | Масса, г | Граней |
|---|---|---|
| передняя половина | 212.7 | 232 384 |
| задняя половина | 72.1 | 65 034 |
| задняя часть нижней обоймы | 2.6 | 1 580 |
| задняя часть верхней обоймы | 4.3 | 988 |
| **итого** | **291.7** | сплошной вариант 416.8 г |

Материал PETG Anodised Teal, 1.27 г/см³. На выходе zip с 3MF (или STL) по каждому телу и `masses.json`, плюс отдельный 3MF для любого тела. Превью упрощено с допуском 0.3 мм и стало в 8 раз легче: 1.1 МБ вместо 8.7 МБ.

## Этап 8. Интерфейс

- На сайте две вкладки: «Below knee» (прежний конфигуратор, не менялся) и «Above knee».
- В новой вкладке все инструменты дизайна прежние: пресеты, узор, картинка, рельеф, маска, отделка, материал. Добавлены:
  - сглаживание поверхности;
  - группа «Leaves on the back»;
  - группа «Attachment»: шов, магниты, обоймы, отверстия, болт;
  - список деталей с массами и кнопкой 3MF у каждой;
  - переключатель разнесённого вида.
- Пределы ползунков приходят с сервера и двигаются вместе с геометрией.

## Этап 9. Тесты

`tests/test_transfemoral.py` + `tests/tf_properties.py`: 26 тестов, все проходят (`TF_EXAMPLES=6`, 4 мин). Прежний набор: 119 тестов, все проходят.

Корпус `tests/regressions/tf_corpus.jsonl` содержит 15 найденных контрпримеров. Все исправлены, все прогоняются заново при каждом запуске. Виды дефектов:
1. Скруглённые углы прямоугольного отверстия срезали прямые углы модуля.
2. Полка упиралась в трубу у лодыжки.
3. Вырез считался на двух глубинах, а заметённое бедро по глубине не монотонно.
4. Гравировка на тонкой стенке оставляла меньше MIN_STRUT.
5. Магнит оставался там, где полка уже обрывалась.
6. Утолщение и полоса полки встречались под швом на вогнутых местах.
7. Ошибки самих проб: двойной счёт луча через общее ребро и косые хорды через углы деталей. Пробы толщины исключают кромки деталей ±3 мм и глубже верха полки, это прямо записано в `walls()`.

## Листья на задней половине (по запросу)

- Переключатель «Large leaves instead of cells» заменяет узор на задней половине несколькими крупными листьями, от 1 до 7.
- Листья стоят рядами по задней средней линии: один на линии или зеркальная пара.
- Лист вырезается по силуэту (округлое основание, острый кончик, зубчатый край), центральная и боковые жилки остаются перемычками. Боковых жилок добавляется столько, чтобы каждая доля укладывалась в допустимый пролёт стенки.
- Где места не хватает, ряд уменьшается. Если не помещается и маленький, ряд выпадает целиком, вместе с парой, и об этом появляется заметка.

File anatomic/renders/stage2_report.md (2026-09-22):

# Этап 2 — ось колена и сечения протеза

Ось колена: z = 213.0 мм в системе этапа 1 (pylon top + 230 mm assembly height - 17 mm dome-to-centre), вперёд-назад y = -8.4 мм.
Купол модуля z = 230.0, центр пирамиды z = 220.0.

Начало координат с этого момента — на оси колена, z вниз отрицательный,
x вдоль оси колена, y вперёд.

## Проверка положения оси

Независимая проверка: по инструкции (bench alignment, стр. 5) линия
нагрузки проходит через центр колена, то есть пилон должен стоять под
осью. Центр пилона по глубине y = -2.6 мм при оси y = 0 — сходится.

Вбок пилон смещён на 11 мм от оси колена. Это настоящее смещение сборки, а не ошибка: оно держится
постоянным по всей длине пилона. Оболочку надо строить вокруг линии
центров сечений, а не вокруг вертикали через ось колена.

Обувь начинается на z = -430 мм: ниже этого сечения — кроссовок,
а не протез, и низ оболочки должен быть выше.

## Таблица сечений

| z, мм | ширина, мм | толщина, мм | центр x | центр y | макс. радиус |
|---|---|---|---|---|---|
| 0 | 74.8 | 83.2 | -0.0 | -0.0 | 51.0 |
| -10 | 73.1 | 72.7 | -4.9 | 8.4 | 56.4 |
| -20 | 73.7 | 67.1 | -4.9 | -8.7 | 49.2 |
| -30 | 73.7 | 84.0 | -8.0 | -16.2 | 52.1 |
| -40 | 77.3 | 86.0 | -3.4 | -12.0 | 51.9 |
| -50 | 74.8 | 84.6 | -2.7 | -12.6 | 52.0 |
| -60 | 74.9 | 77.9 | -5.4 | -17.6 | 52.7 |
| -70 | 73.9 | 76.1 | -4.7 | -15.9 | 50.6 |
| -80 | 70.7 | 72.3 | -8.4 | -18.9 | 50.0 |
| -90 | 69.9 | 73.9 | -10.2 | -20.8 | 50.9 |
| -100 | 68.2 | 72.5 | -7.4 | -1.1 | 46.8 |
| -110 | 65.4 | 68.6 | -6.7 | -1.2 | 44.3 |
| -120 | 63.9 | 65.3 | -6.0 | -3.2 | 40.5 |
| -130 | 59.7 | 62.1 | -7.8 | -0.3 | 40.1 |
| -140 | 57.2 | 59.0 | -9.7 | -1.1 | 36.9 |
| -150 | 55.4 | 56.5 | -10.2 | -0.9 | 35.5 |
| -160 | 47.1 | 50.6 | -9.5 | -1.8 | 32.6 |
| -170 | 43.9 | 48.6 | -9.7 | -3.1 | 30.2 |
| -180 | 42.8 | 45.5 | -9.7 | -1.7 | 30.5 |
| -190 | 40.3 | 45.6 | -12.7 | -12.1 | 25.0 |
| -200 | 41.0 | 46.7 | -12.8 | -9.9 | 28.0 |
| -210 | 38.0 | 42.5 | -10.3 | -2.9 | 27.0 |
| -220 | 37.2 | 36.3 | -12.3 | -3.3 | 24.8 |
| -230 | 36.8 | 36.2 | -12.8 | -4.8 | 23.1 |
| -240 | 36.3 | 36.4 | -12.0 | -3.1 | 24.9 |
| -250 | 35.7 | 36.5 | -11.7 | -2.9 | 25.2 |
| -260 | 35.0 | 36.9 | -11.8 | -2.7 | 25.0 |
| -270 | 34.5 | 36.9 | -11.8 | -4.1 | 23.6 |
| -280 | 33.9 | 37.1 | -11.8 | -3.8 | 23.5 |
| -290 | 33.6 | 37.5 | -11.9 | -5.4 | 22.3 |
| -300 | 33.3 | 37.4 | -11.8 | -4.9 | 22.9 |
| -310 | 32.7 | 37.3 | -11.7 | -4.0 | 23.7 |
| -320 | 32.4 | 36.7 | -11.4 | -3.5 | 23.2 |
| -330 | 35.1 | 36.2 | -10.5 | -2.4 | 22.3 |
| -340 | 33.0 | 32.5 | -9.0 | 0.5 | 21.9 |
| -350 | 31.2 | 32.8 | -9.3 | -1.4 | 21.1 |
| -360 | 34.2 | 35.3 | -9.0 | 1.3 | 22.4 |
| -370 | 34.5 | 36.7 | -9.9 | -0.5 | 22.5 |
| -380 | 39.8 | 48.1 | -12.9 | -7.1 | 26.7 |
| -390 | 38.6 | 49.4 | -10.7 | -8.3 | 27.9 |
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

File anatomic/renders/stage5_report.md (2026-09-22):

# Этап 5 — сгибание и форма кромки

Бедро заменено телом вращения вокруг оси колена: радиус на каждой высоте
снят со скана вокруг собственного центра сечения плюс 2 мм запаса. У колена 48.3 мм, наверху 81.2 мм.

Кромка не подбирается, а решается: каждая точка несрезанной поверхности
прогоняется через все углы сгибания, и кромка ставится на последнюю
высоту, которую столбец переживает. Получается максимум оболочки,
который допускает сустав.

| где | высота кромки, мм |
|---|---|
| перёд | **+18** |
| медиально | +18 |
| латерально | -6 |
| зад-медиально | -30 |
| **зад** | **-64** |
| зад-латерально | -46 |

Колено закрыто на 59% окружности (кромка выше оси колена).

| угол | пересечение | точек внутри |
|---|---|---|
| 0° | нет | 0 |
| 5° | нет | 0 |
| 10° | нет | 0 |
| 15° | нет | 0 |
| 20° | нет | 0 |
| 25° | нет | 0 |
| 30° | нет | 0 |
| 35° | нет | 0 |
| 40° | нет | 0 |
| 45° | нет | 0 |
| 50° | нет | 0 |
| 55° | нет | 0 |
| 60° | нет | 0 |
| 65° | нет | 0 |
| 70° | нет | 0 |
| 75° | нет | 0 |
| 80° | нет | 0 |
| 85° | нет | 0 |
| 90° | нет | 0 |
| 95° | нет | 0 |
| 100° | нет | 0 |

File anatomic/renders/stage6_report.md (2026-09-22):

# Этапы 4–6 — поверхность  сгибание  результат

## Этап 4. Поверхность

Оболочка идёт от z = -370.0 мм (на 10 мм выше начала адаптера стопы 
z = -380.0) до z = 0.0 мм (ось колена). 186 сечений с шагом 2 мм.

Каждое сечение — форма голени MakeHuman на соответствующей относительной высоте 
отмасштабированная так  чтобы вместить сечение протеза плюс 5.0 мм.
Там  где анатомический силуэт уже протеза  он раздувается ровно на нехватку:
максимум 15.8 мм. Самое широкое место на z = -42.0 мм 
радиус 61.8 мм; самое узкое — 24.8 мм.

Масштаб по высоте сначала расширяется скользящим максимумом  потом размывается.
Наоборот нельзя: размытие само по себе просадило бы поверхность обратно в зазор
на локальном пике.

## Этап 5. Сгибание

Бедро — тело вращения вокруг оси колена  радиус на каждой высоте снят со скана
вокруг собственного центра сечения: 49.1 мм у колена 
до 83.9 мм наверху. Один цилиндр не годится — у колена он
был бы вдвое толще правды  а выше смещён вбок  потому что на скане человек сидит.

Вырез рос от 40 мм за 57 шагов по 2 мм и
остановился на **152 мм**. Вбок кромка опустилась на
70 мм: при глубоком сгибании бедро не только сзади от
оболочки  но и сбоку  поэтому вырез открывается вширь  а не только вглубь.

Столкновений: 0 из 27 углов (0…130° с шагом 5°).

## Этап 6. Результат

`cover_anatomic.stl` — 129 600 треугольников  замкнутая  обход согласован 
эйлерова характеристика 0 (труба с двумя отверстиями — так и должно быть).
Объём 196.0 см³  масса 243.0 г при плотности PLA 1.24 г/см³.
Высота 336.8 мм. manifold3d считает тот же объём: 196.0 см³.

Проверки на готовом теле  а не на поверхности  из которой оно построено:

| Проверка | Результат |
|---|---|
| минимальный зазор до протеза от внутренней стенки | **2.27 мм** при требуемых 2.0 |
| сечений проверено | 186 |
| столкновений при сгибании | **0** из 27 |

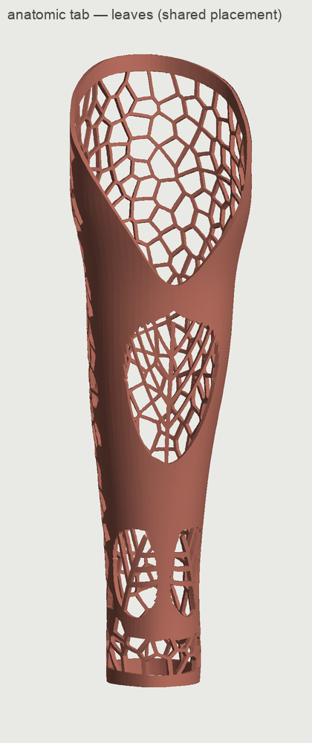
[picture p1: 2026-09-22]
anatomic/renders/anat_lv_on.png

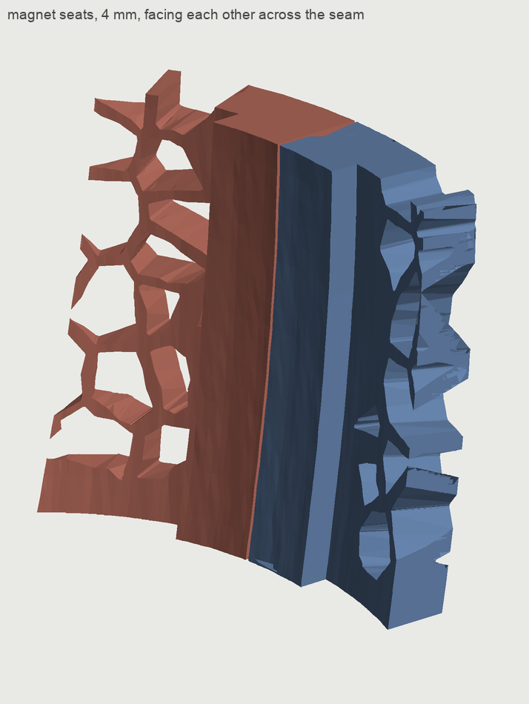
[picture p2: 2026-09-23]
renders/fasteners/magnet_seats.png

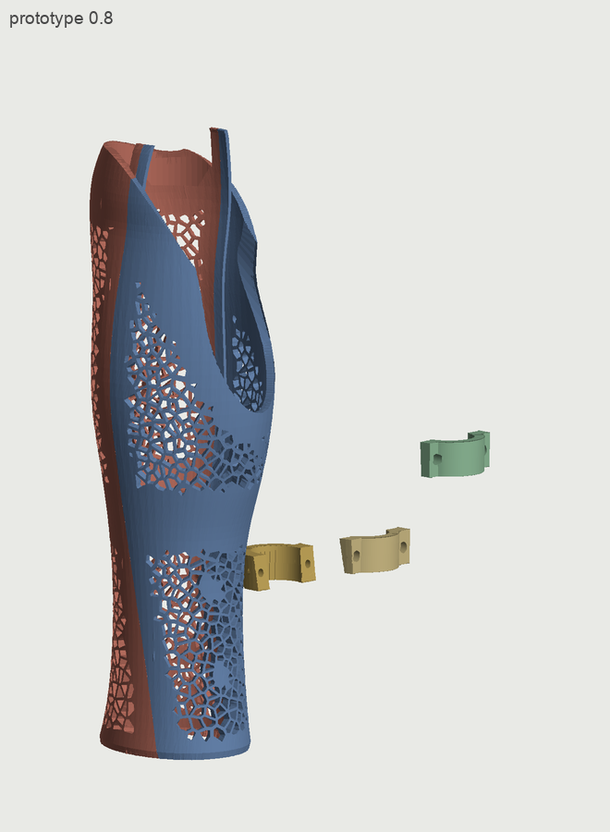
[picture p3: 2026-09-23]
renders/fasteners/proto_0.8.png

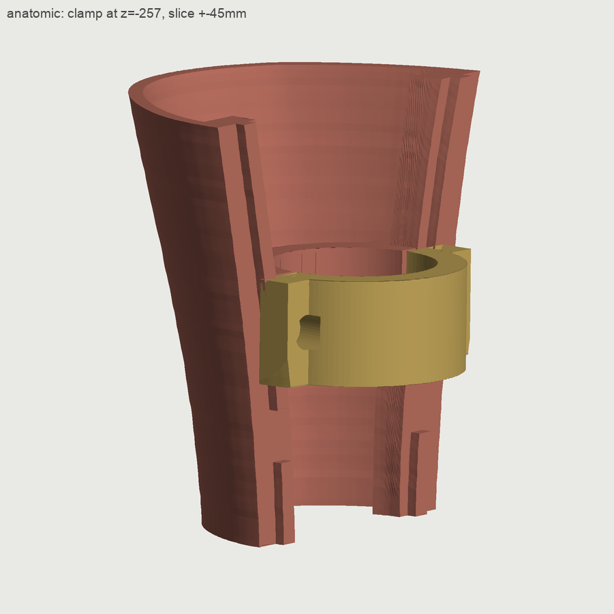
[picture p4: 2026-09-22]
renders/fasteners/anatomic_cut_three_quarter.png

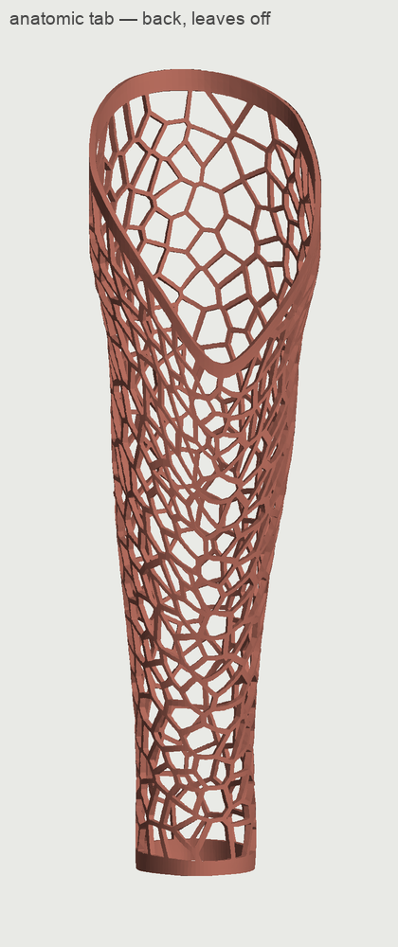
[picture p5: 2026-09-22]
anatomic/renders/anat_noleaves_back.png

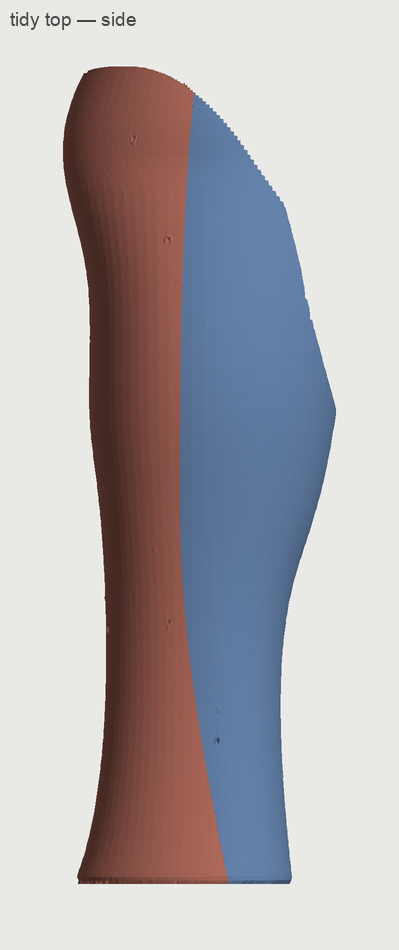
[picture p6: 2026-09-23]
renders/fasteners/iter2_top_side.png

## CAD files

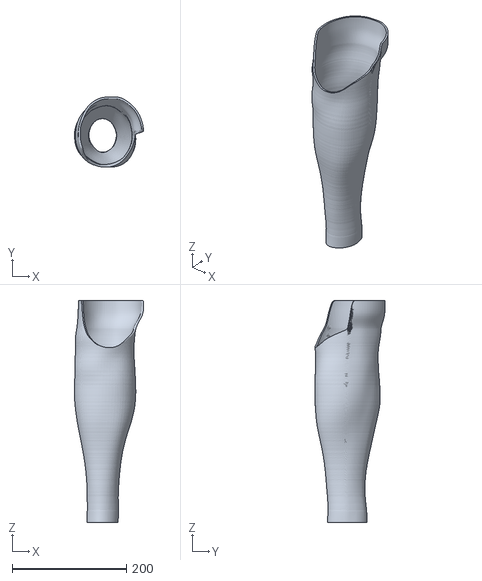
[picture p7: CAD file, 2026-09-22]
cover_anatomic.stl
120.8 x 123.1 x 388.0

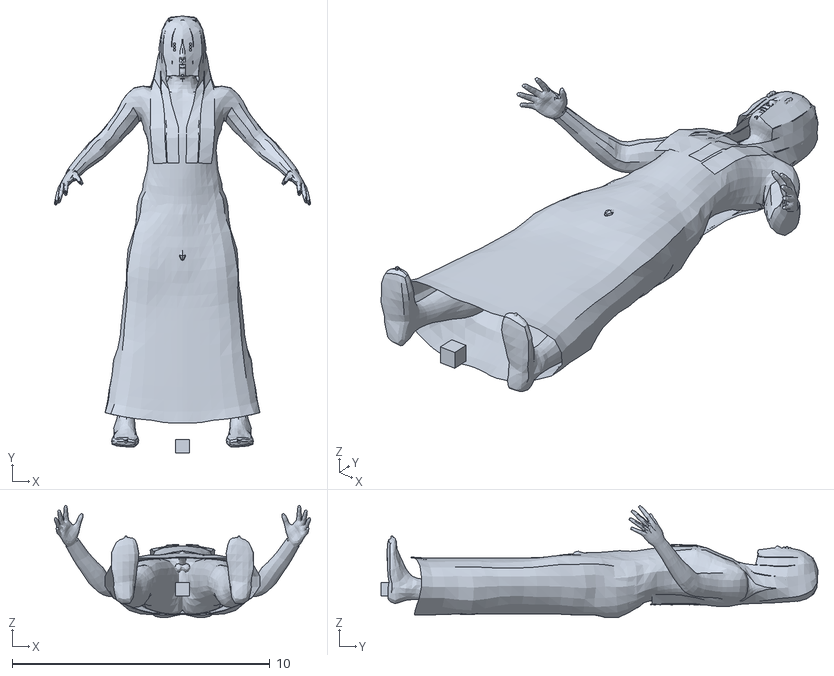
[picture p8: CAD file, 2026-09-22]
data/makehuman_base.obj
9.95 x 16.9 x 4.36

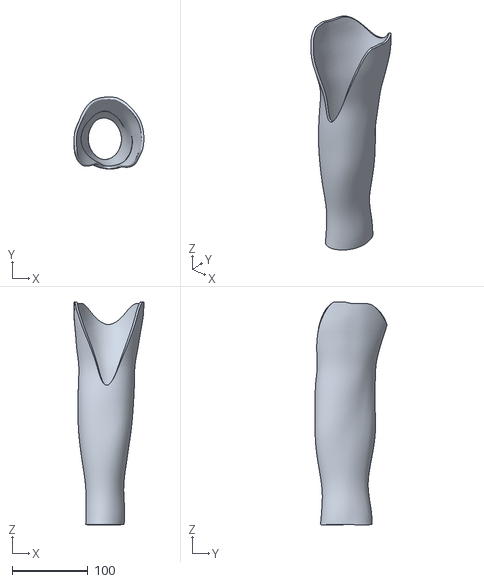
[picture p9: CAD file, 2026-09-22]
cover_reference.stl
92.2 x 95.0 x 294.6

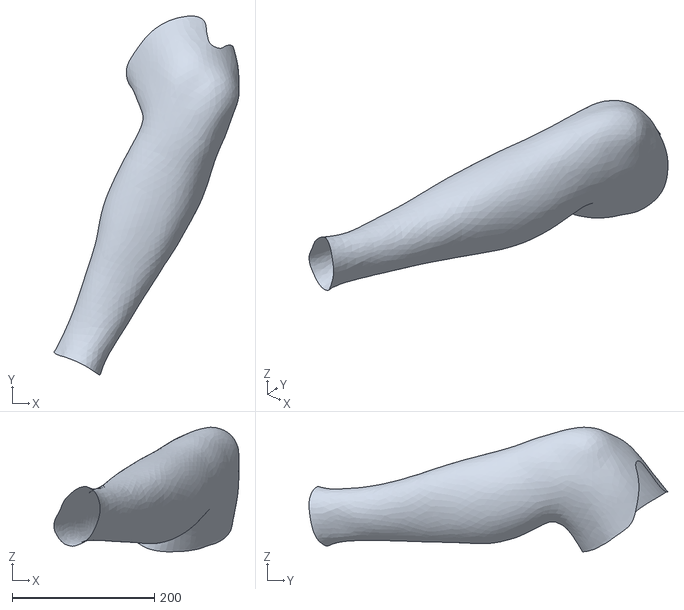
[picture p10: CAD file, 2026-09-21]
data/оболочка.stl
259.9 x 504.4 x 175.1

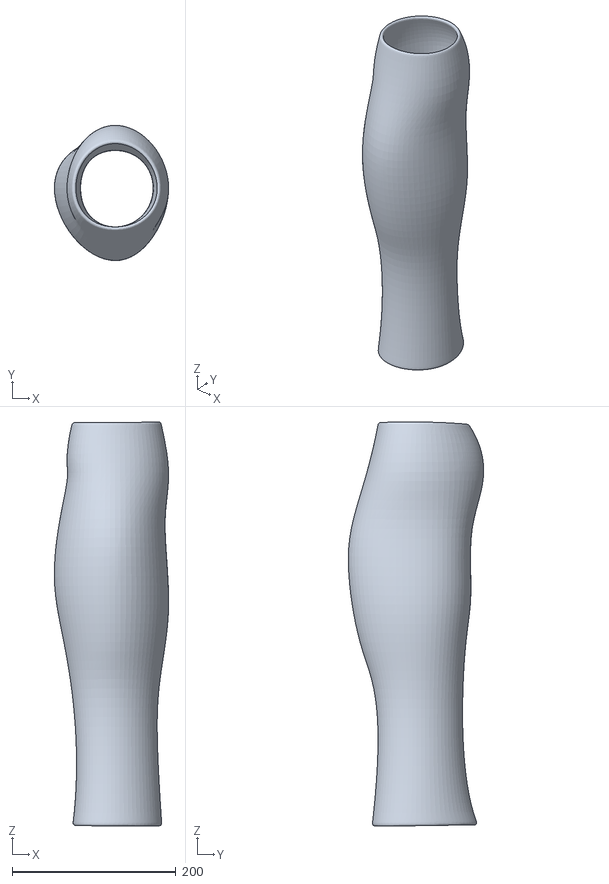
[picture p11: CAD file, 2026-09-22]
Cover new.stl
139.4 x 165.1 x 493.1

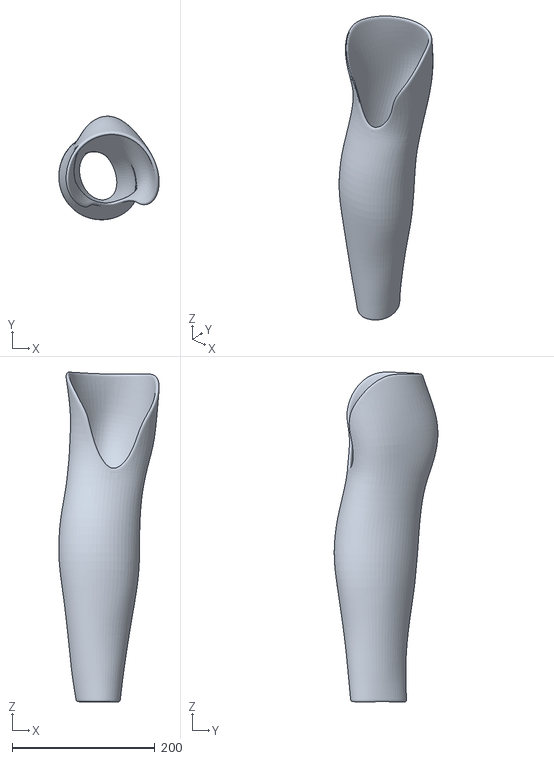
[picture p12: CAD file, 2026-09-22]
cover ready iteration 1.stl
140.5 x 145.0 x 461.8

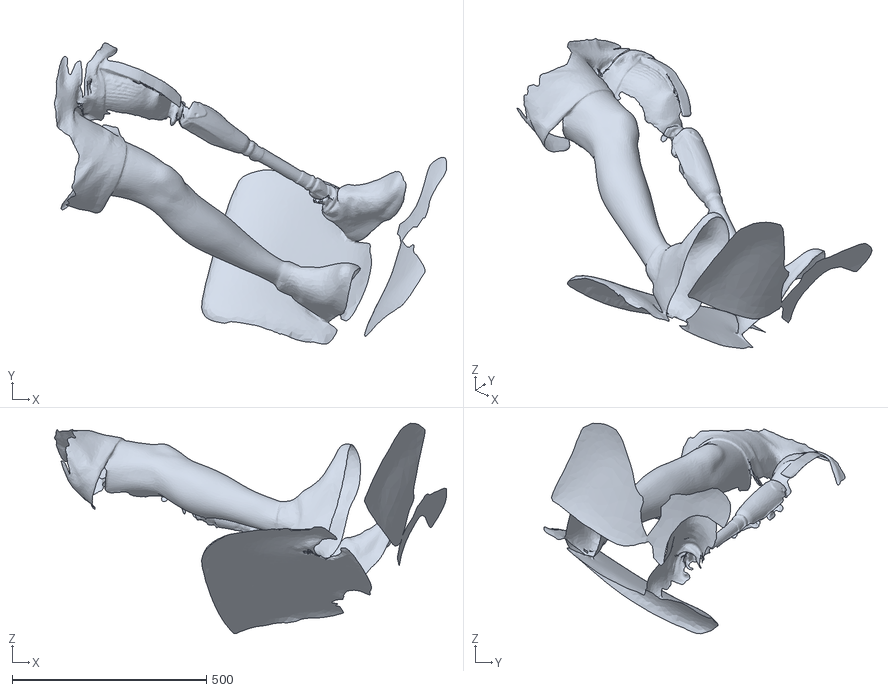
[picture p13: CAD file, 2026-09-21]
TEST - Everything scan.stl
1007.8 x 774.2 x 541.3

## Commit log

2026-09-11 Prosthetic cover configurator
    A web configurator for cosmetic covers for a below-knee prosthesis: move the
    sliders, watch the cover turn, read its weight, download a print file.
    The point of the build is that a design which fails a printability check is
    not reachable. Every constraint is built into the generator rather than
    checked afterwards, so no combination of sliders can produce one, and the
    interface never tells anybody their design was rejected.
    A design is four things multiplied together - the cell field, the operation,
    the mask and the finish - and the holes can take their shape from an uploaded
    picture, which changes what a hole looks like without touching where the cell
    field pu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
2026-09-21 Transfemoral cover tab, before the knee was evened out
    The second pipeline: the outer surface comes from a scan of the sound
    leg rather than from sliders, and the cover comes out as four printable
    bodies around a College Park Capital knee.
    This is the state the slices were still crooked in. Above the knee the
    probe rays that built the radius grid start missing — the knee is bent
    and the thigh shadows the back of it — and the holes left behind were
    filled, so rows two apart sit millimetres apart. It shows as a wavy top
    rim and a rippled surface over the upper third. Kept as its own commit
    so that shape can be looked at and diffed against the fix on top.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
    [TEST - Everything scan.stl, оболочка.stl]
2026-09-21 Even out the knee so the slices stop coming out crooked
    Above z = 40 the scan's radius grid is shadow, not leg: the knee is bent
    and the thigh hides the back of it, so only part of each ring was ever
    probed and the rest was filled in. The slices that came out of it stepped
    several millimetres between neighbouring rows, which read as a wavy rim
    and a rippled upper third.
    `even_out_knee` dilates each ring out to a smooth envelope and rounds
    what is left, so the surface is built outward and never shaved back.
    Shaving would even the rim just as well, but this surface is the cover's
    outer skin and its wall goes inward: every millimetre taken off here is
    a millimetre off the clearance around the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
2026-09-22 Anatomic shank and modelled-cover tabs, fasteners, hardware scan
    Two more covers beside the two that were here. The anatomic shank is built
    offline in `anatomic/` from the prosthesis scan and a MakeHuman shank, stage by
    stage, and served through `backend/anatomic_*`. Iteration 1 and 2 take a cover
    modelled in Rhino as a file and hand it to the configurator, with the fastener
    work in `backend/fasteners/` and the hardware read off the scan by
    `tools/prepare_hardware.py`.
    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
    [Cover new.stl, cover ready iteration 1.stl, cover_anatomic.stl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]
2026-09-23 Knee notch, scaled prototype, and the glue-in web for the printed half
    The cover crosses the knee, so the back of it is cut away wide enough for
    130 degrees of flexion and a shroud stands in the opening. The prototype
    module prints whatever Iteration 2 is showing at a fraction of its size,
    leaving the wall, magnets and clamps in millimetres so they stay real.
    tools/make_glue_in_web.py builds the cross-wall as a glue-in part for the
    front half that was printed before the lower clamp existed.

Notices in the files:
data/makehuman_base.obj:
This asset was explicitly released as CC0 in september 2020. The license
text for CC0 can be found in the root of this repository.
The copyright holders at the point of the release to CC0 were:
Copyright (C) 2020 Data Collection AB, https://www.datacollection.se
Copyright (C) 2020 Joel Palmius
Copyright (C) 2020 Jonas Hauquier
